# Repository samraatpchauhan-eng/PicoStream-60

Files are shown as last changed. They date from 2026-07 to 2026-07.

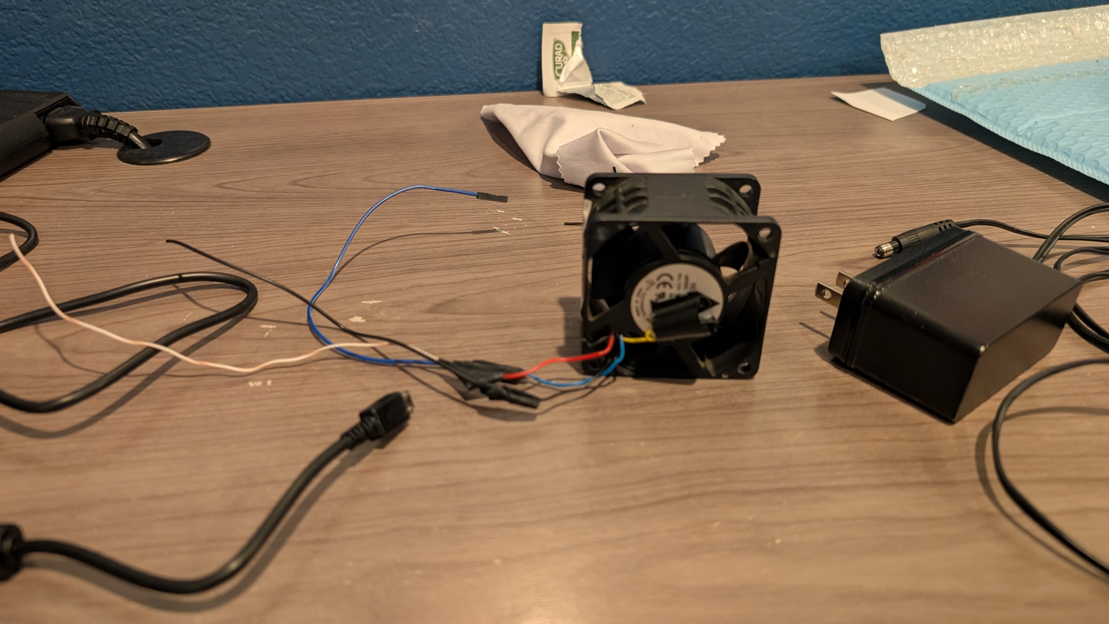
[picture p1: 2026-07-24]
Assets/PXL_20260724_002609780.jpg

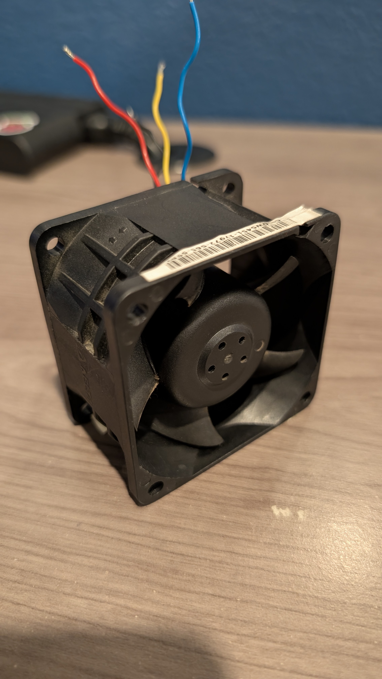
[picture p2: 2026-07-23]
Assets/PXL_20260723_030500156.jpg

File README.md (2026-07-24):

# PicoStream-60

PicoStream-60 is a desk wind tunnel use for analyzing drag force on different objects, such as Hotwheels cars, scaled airplane models, or even custom geometries made by someone! It's powered by the Raspberry Pi Pico rp2040 microcontroller. I designed this because as someone who is deeply passionate about aerospace engineering, I though this would be a good project that I could even learn from, and even use in the future.

## Features:
* **Powerful Brushless Fan**  PicoStream-60 features a powerful 60mm delta fan intended for server cooling, and can spin up to 12,000 rpm.
* **Adjustable Fan Speed:** Via an ec11 digital encoder, the fan can be adjusted for different kinds of enviornments, and items being tested, and features around 33 indivual speed settings.
* **Scientifically Accurate Design:** I engineered PicoStream-60 to follow real world principles when designing a wind tunnel, including a honeycomb mesh panel to reduce air turbulence, and an inlet which reduces in area size to streamline airflow.
* **Analysis Feature** This wind tunnel has the ability to record and display live time drag force in grams on an external serial monitor (given, that you will need your own external display) for further drag force analysis

---

## CAD Model
I designed the overall wind tunnel structure on Fusion360, and have decided to 3d print the parts using standard PLA at 20% infill. The assembly also has nice rounded curves to make it more presentable

Main_Housing_2026-Jul-23_05-11-49AM-000_CustomizedView10790424624

---

### Schematic Design
*The circuit schematic mapping the switch, digital encoder, and Load Cell to the microcontroller.*



---

## How to Assemble
1. Join the mesh and mesh mount together with the m3 screws
2. Attatch the Fan to the Fan mount using the m4 screws, and hot glue the Pico microcontroller, Switch and Rotary encoder to the Fan Mount aswell
3. Glue the load cell into the hole in the carriage halfway, with the end with the wires sticking out (See CAD model to locate mounting hole)
4. Hot glue the rest of the parts together, and make sure to line each gap with duct tape to keep the wind tunnel assembly extra air tight
5. Wire up! (See schematic for reference)
6. Now move onto "How to Flash"!
---

## How to Flash
1. Press and hold the physical **BOOT** button on the Pico controller board.
2. Connect the USB cable while holding the button, then release it.
3. A virtual drive will mount to your operating system.
4. Drag and drop the `sketch_jul22a.ino.uf2` binary file directly onto the root of the drive.
5. The device will automatically flash, reboot, and initialize as an operational device.

---

## AI Attribution Note
**Please Note that AI was utilized for some basic project planning and debugging of the firmware in Arduino IDE**

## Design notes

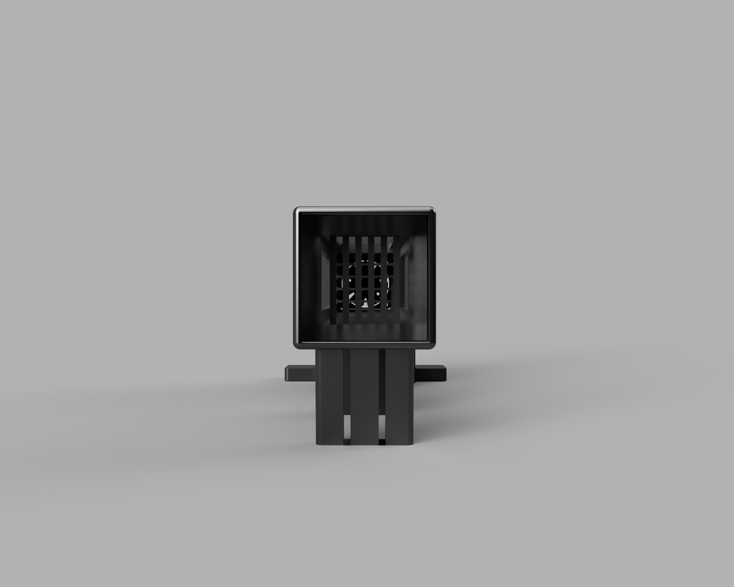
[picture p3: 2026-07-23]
Assets/Main_Housing_2026-Jul-23_05-12-39AM-000_CustomizedView50093851676.png

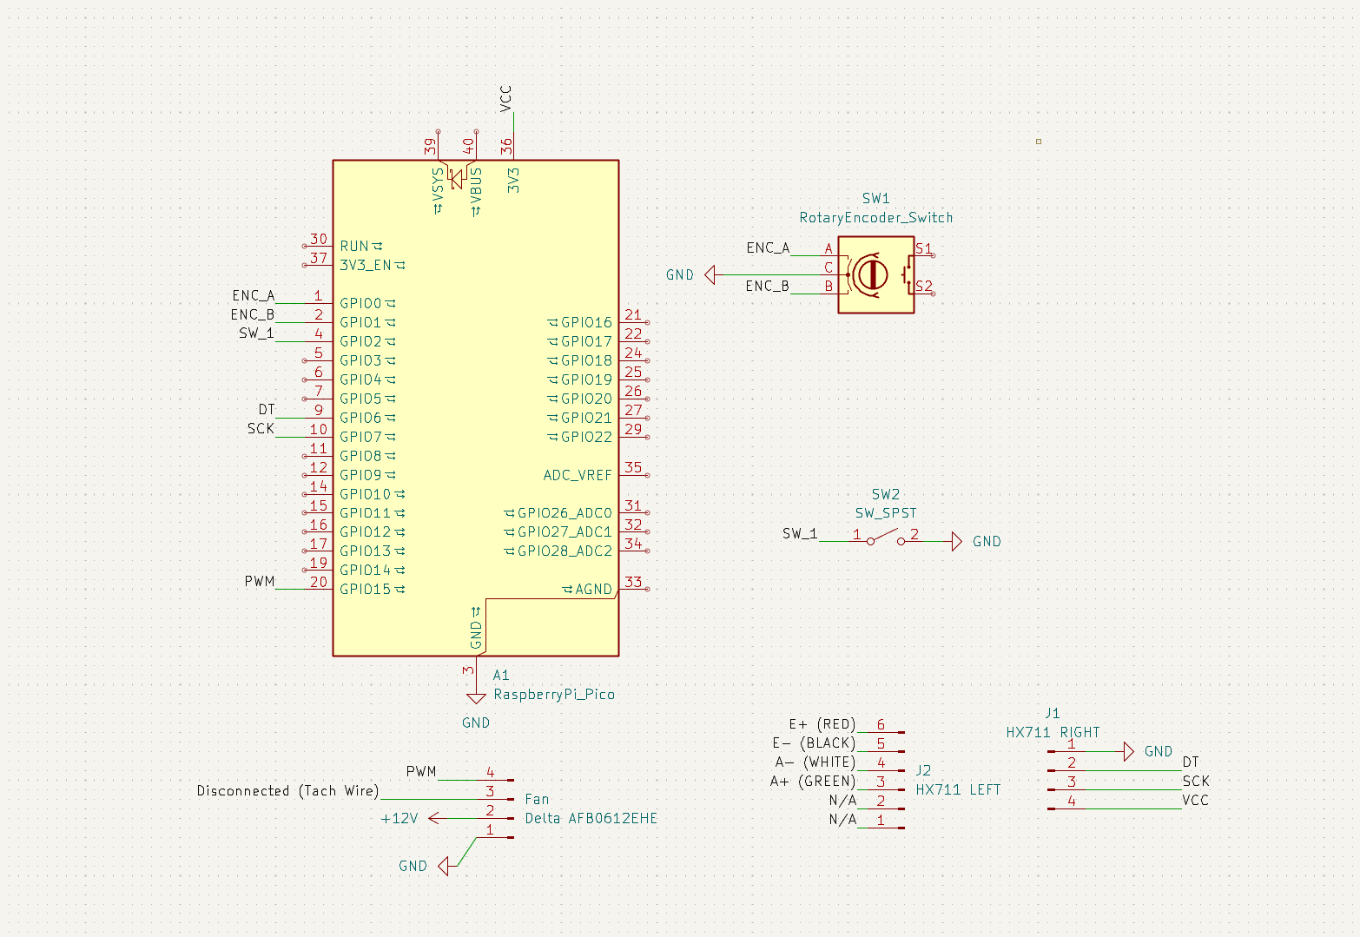
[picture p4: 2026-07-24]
Assets/Screenshot 2026-07-23 190917.png

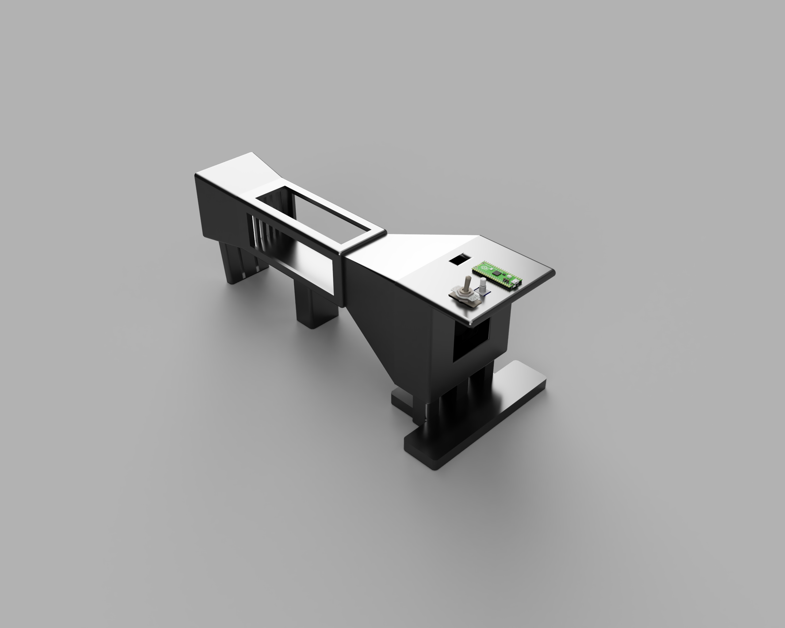
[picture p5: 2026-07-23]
Assets/Main_Housing_2026-Jul-23_05-12-07AM-000_CustomizedView18915450462.png

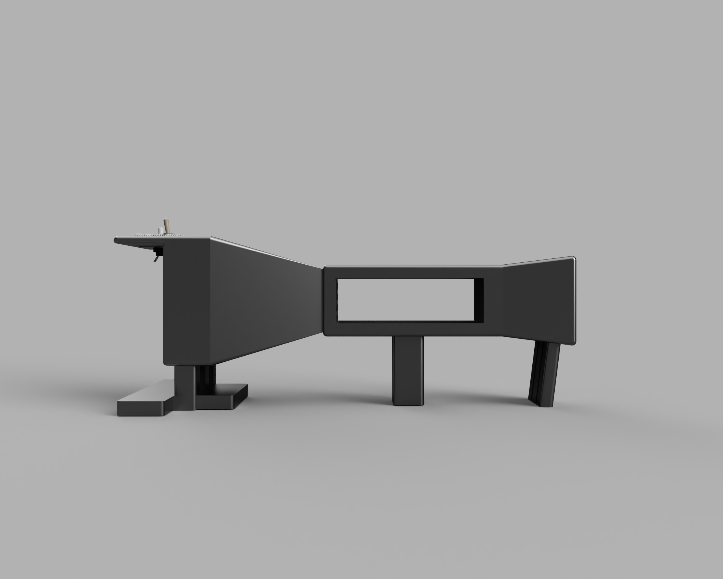
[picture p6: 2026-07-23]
Assets/Main_Housing_2026-Jul-23_05-10-43AM-000_CustomizedView26035609281.png

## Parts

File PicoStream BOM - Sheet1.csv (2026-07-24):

Name | Price | Quantity | Link
Delta AFB0612EHE 60mm x 38mm brushless fan | $21.47 | 1 | Fan
Raspberry Pi Pico 2020 rp2040 | $11.99 | 1 | Pico
EC11 digital encoder | $9.99 | 1 | ec11
KN3C-101 toggle switch | $7.99 | 1 | switch
m3 10mm screws | $9.99 | 4 | screws
m4 30mm screws | $5.99 | 4 | screws
120V 3A power supply with female adapter | $9.99 | 1 | power supply
Load Cell Weighing Sensor with amplifier | $9.99 | 1 | Load Cell
3d prints of the wind tunnel | ~ $15.00 | 1 copy needed | N/A
TOTAL COST: ~ $102.40

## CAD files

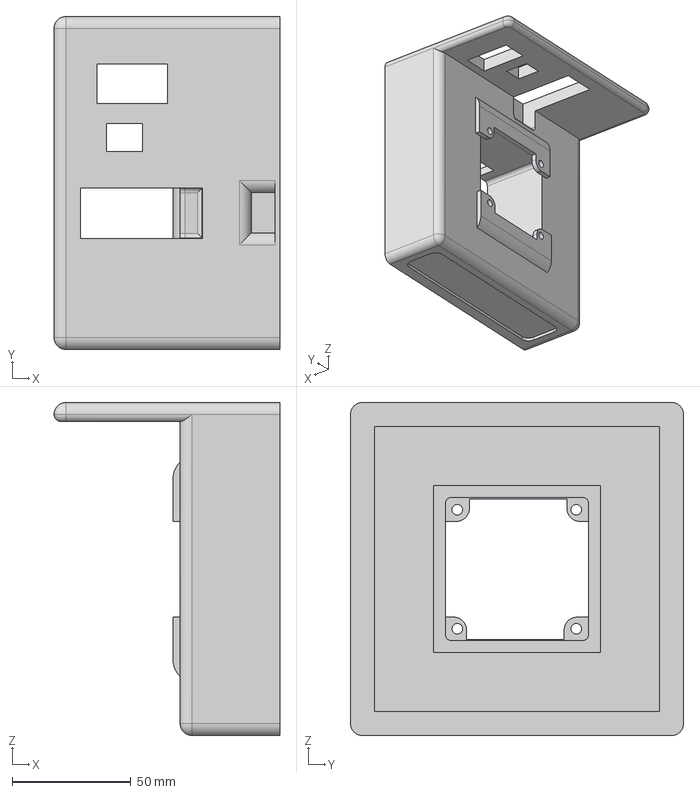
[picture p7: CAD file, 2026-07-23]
CAD/Fan Mount.step
95.0 x 140.0 x 140.0 mm

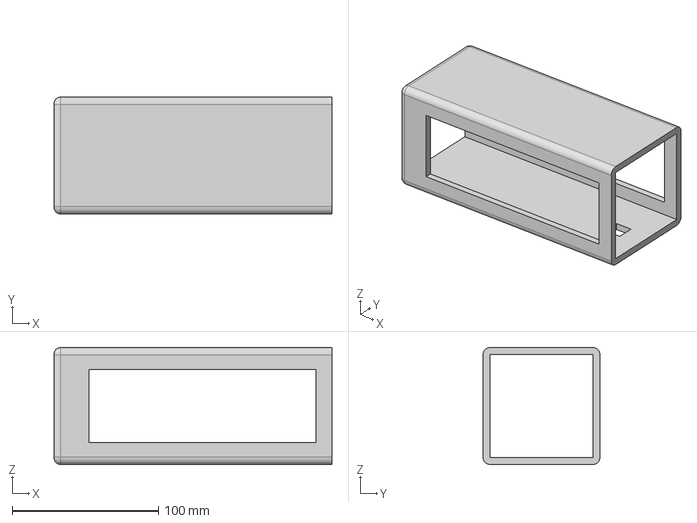
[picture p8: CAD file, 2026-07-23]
CAD/Carriage.step
190.0 x 80.0 x 80.0 mm

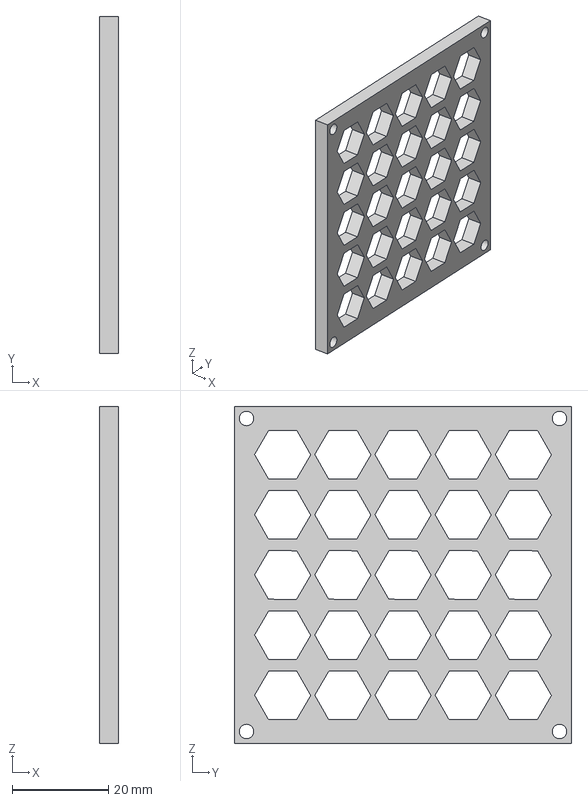
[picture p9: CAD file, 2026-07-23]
CAD/Inlet Mesh.step
4.00 x 70.0 x 70.0 mm

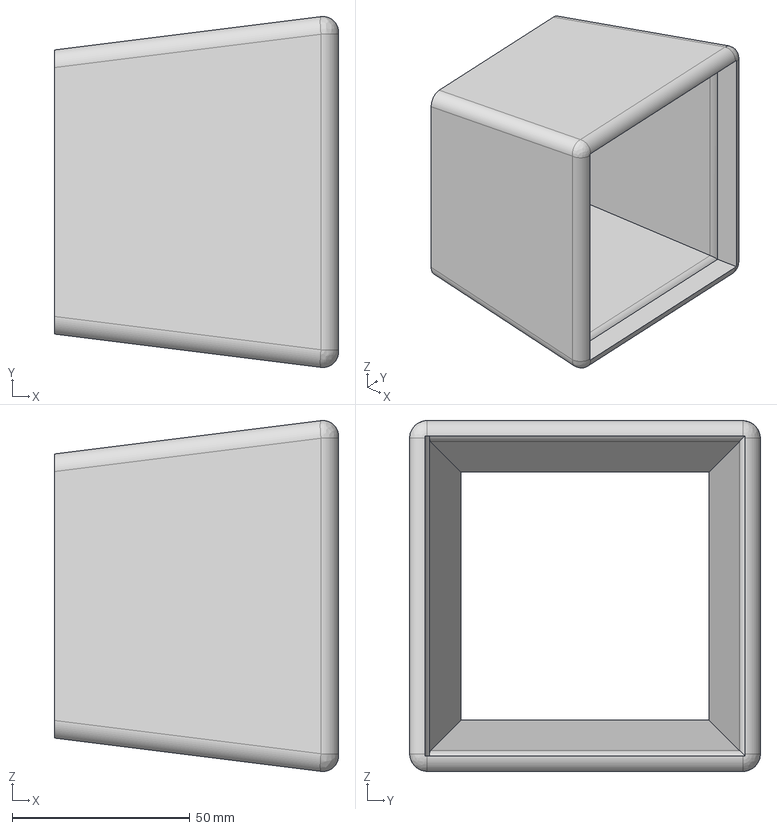
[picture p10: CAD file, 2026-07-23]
CAD/Outlet.step
80.0 x 98.8 x 98.8 mm

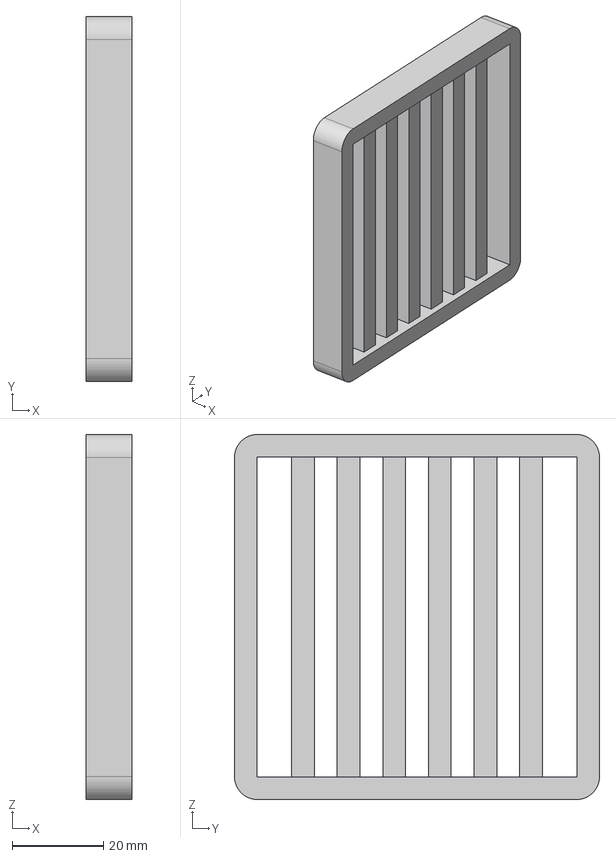
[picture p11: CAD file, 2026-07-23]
CAD/Outlet Mesh Mount.step
10.0 x 80.0 x 80.0 mm

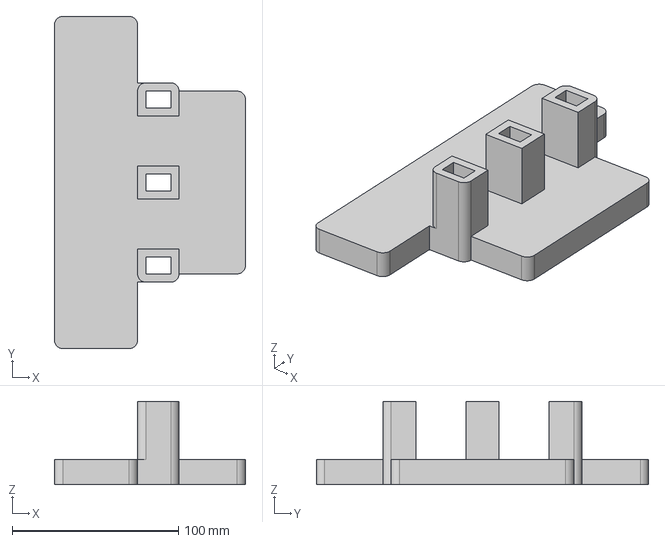
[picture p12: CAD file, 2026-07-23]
CAD/Inlet Legs.step
115.0 x 200.0 x 50.0 mm

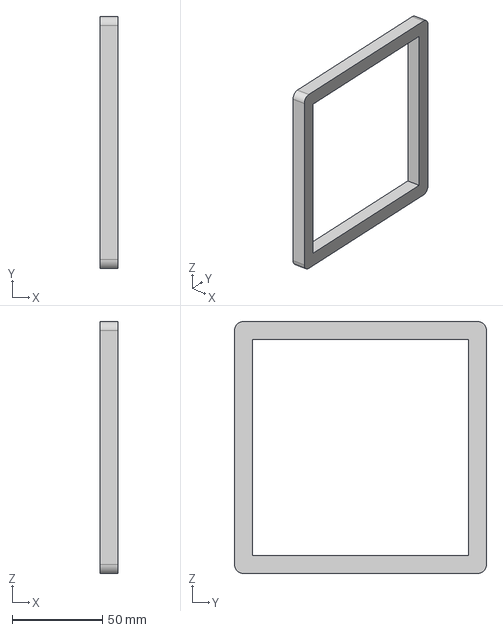
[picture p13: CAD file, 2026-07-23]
CAD/Inlet Transition.step
10.0 x 140.0 x 140.0 mm

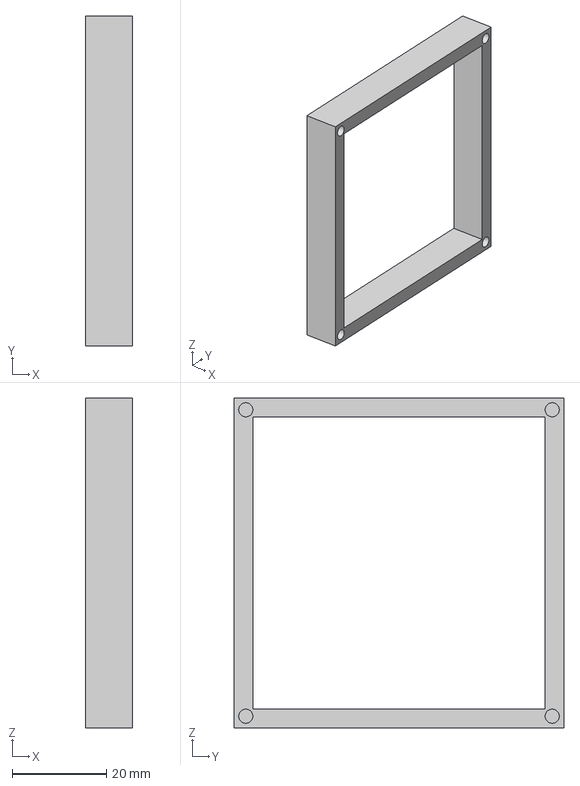
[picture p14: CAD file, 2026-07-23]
CAD/Mesh Mount.step
10.0 x 70.0 x 70.0 mm

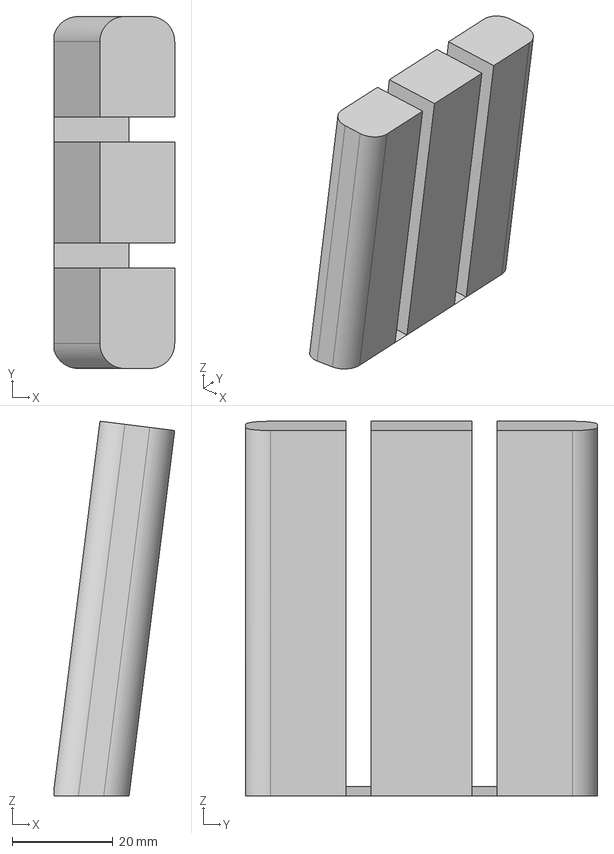
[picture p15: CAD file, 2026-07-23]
CAD/Outlet Legs.step
24.0 x 70.0 x 74.5 mm

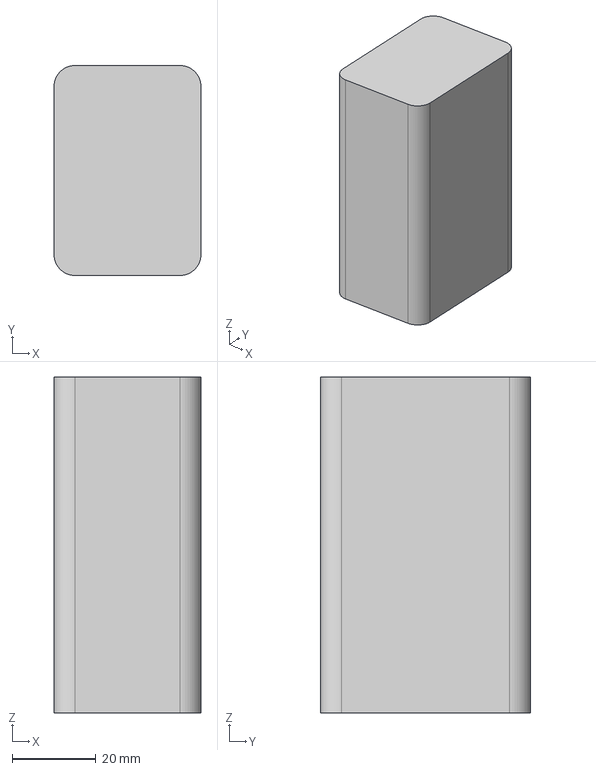
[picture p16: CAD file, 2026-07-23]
CAD/Carriage Legs.step
35.0 x 50.0 x 80.0 mm

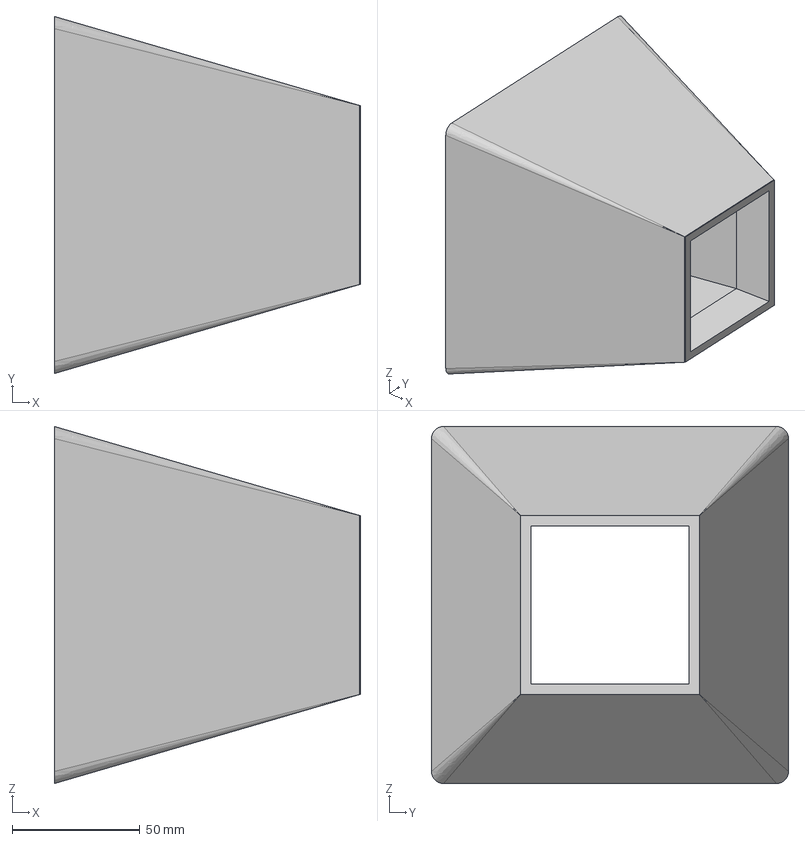
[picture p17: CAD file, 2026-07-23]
CAD/Transition Cover.step
120.0 x 140.0 x 140.0 mm

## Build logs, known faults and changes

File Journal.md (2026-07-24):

**7/22/2026**
 - I just came back from outpost, so I am feeling extra motivated to build this thing! I spent today mainly cadding up the physical components of the wind tunnel via Fusion360.
 
 

 - I also spent some time planning out features. Im gonna use a delta 60mm brushless fan to move the air, a toggle switch to turn it on and off, and a ed11 digital encoder to adjust the fan speed! This is going to be powered by a RP Pico rp2040!






So far, progress is looking great!!!

<hr>

**7/23/2026**
 - Today was quite a long work session! I was able to make some minor tweaks to the wind tunnel assembly so that it fits all the wiring and harware compenents securely. I did have a bit of a hard time selecting the pressure sensor, but ended up going with a standard HX711 aluminum load cell i found on amazon. I also was able to create the firmware for the pico microcontroller, and found no issues uploading the firmware onto the board, which is good news for me! Finally, I did some basic soldering today, including connecting wire extensions to the delta fan so they can reach the Pico board on top of the wind tunnel.

 - Aluminum Load Cell


 - Firmware (no issues or bugs finally!!!) - Yes, I had to screenshot the code on notepad otherwire i couldnt capture the whole thing in one screenshot 😭


 - Soldered and taped up extensions for the delta fan


<hr>

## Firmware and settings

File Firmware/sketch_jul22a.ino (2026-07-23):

  #include "HX711.h"

  HX711 scale;
  float calibFactor = 420.0;
  
  const int PIN_ENCODER_A = 0;
  const int PIN_ENCODER_B = 1;
  const int TOGGLE_SWITCH = 2;
  const int HX711_DT = 6;
  const int HX711_SCK = 7;
  const int FAN_PWM = 15;

  int fanSpeed = 0;
  int lastEncStateA;

void setup() {
  pinMode(FAN_PWM, OUTPUT);

  pinMode(TOGGLE_SWITCH, INPUT_PULLUP);
  pinMode(PIN_ENCODER_A, INPUT_PULLUP);
  pinMode(PIN_ENCODER_B, INPUT_PULLUP);

  lastEncStateA = digitalRead(PIN_ENCODER_A);

  analogWriteFreq(25000);
  analogWriteResolution(10);

  scale.begin(HX711_DT, HX711_SCK);
  scale.set_scale(calibFactor);
  scale.tare();
  Serial.begin(115200);
  

}

void loop() {
    if(digitalRead(TOGGLE_SWITCH) == LOW) {
      analogWrite(FAN_PWM, fanSpeed);
    } else {
      analogWrite(FAN_PWM, 0);
    }
    
    int currentA = digitalRead(PIN_ENCODER_A);

    if(currentA != lastEncStateA && currentA == LOW) {
      if(digitalRead(PIN_ENCODER_B) != currentA) {
        fanSpeed += 32;
      } else {
        fanSpeed -= 32;
      }
      fanSpeed = constrain(fanSpeed, 0, 1023);
    }
    lastEncStateA = currentA;

    static unsigned long lastReadTime = 0;
    if(millis() - lastReadTime >= 100) {
      if(scale.is_ready()) {
        float dragGrams = scale.get_units(1);

        Serial.print("Target_PWM:");
        Serial.print(fanSpeed);
        Serial.print(", ");
        Serial.print("Drag Force (grams):");
        Serial.println(dragGrams);
      }
      lastReadTime = millis();
    }
}

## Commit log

2026-07-23 Added 3d print files
    [Carriage Legs.step, Carriage.step, Fan Mount.step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]
2026-07-23 Tweaked CAD to fit load cell / added screw mounts for fan
    [Carriage.step, Fan Mount.step]
2026-07-24 added BOM
    [PicoStream BOM - Sheet1.csv]
2026-07-24 Enhance README with detailed project information
    Expanded project description and added sections for CAD model, schematic design, flashing instructions, and AI attribution.
